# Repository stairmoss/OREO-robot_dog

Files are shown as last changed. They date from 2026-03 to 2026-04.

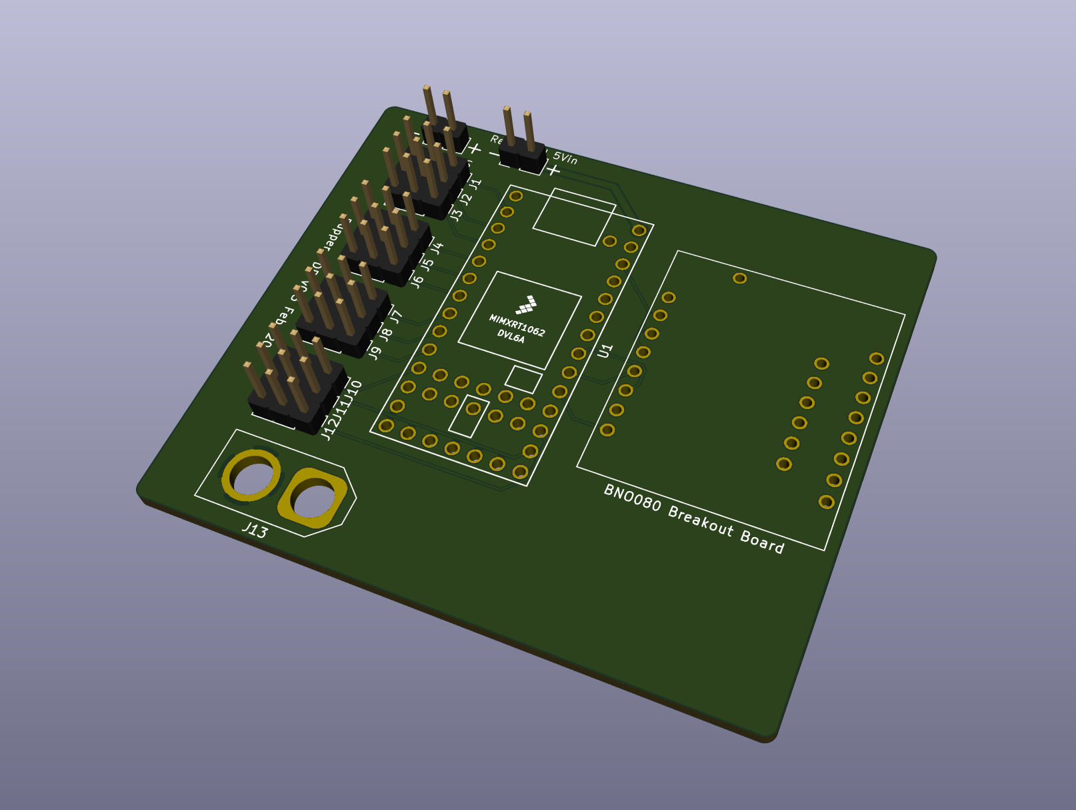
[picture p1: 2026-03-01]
3dpcbmodel.png

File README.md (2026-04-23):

# OREO – ROS Based Quadruped Robot Dog

# OREO V2 – ROS Powered Vision-Based Quadruped Robot  
### Hack Club Advanced Robotics Project

OREO V2 is a next-generation quadruped robot dog powered by a Raspberry Pi 4 and Teensy microcontroller, upgraded from the original ESP32 version into a full ROS-based intelligent robotic platform.

This version adds:

- 🧠 Computer Vision
- 🐾 12 High-Torque (20kg) Servos
- 🤖 ROS 2 Architecture
- 📡 Behavior-Based Control System
- ❤️ Touch Interaction
- 📷 Person Detection & Following

OREO V2 is no longer just a walking robot — it is an intelligent robotic companion platform built under a constrained $395 budget.

---

# 📌 Project Overview

| Item | Description |
|---|---|
| Robot Type | Quadruped (4-legged) |
| Architecture | ROS 2 Modular System |
| Main Computer | Raspberry Pi 4 Model B (4GB) |
| Motor Controller | Teensy Microcontroller |
| Servos per Leg | 3 (Hip, Upper, Knee) |
| Total Servos | 12 × 20kg High Torque |
| Sensors | IMU + Touch Sensor + Camera |
| Frame | 3D Printed Spot Micro Style |
| Power | 2S/3S Li-ion / LiPo Battery |
| Budget | ~$395 USD |
| Difficulty | Intermediate → Advanced |

---

# 🎯 Vision & Purpose

OREO V2 was built to:

- Transition from beginner robotics to ROS-based research structure
- Integrate computer vision into a quadruped platform
- Maintain affordability under strict budget constraints
- Build a modular robotic system expandable to SLAM and AI
- Learn real robotics engineering workflow

This robot is designed as a stepping stone toward advanced robotic systems.

---

# 🧠 System Architecture

OREO V2 uses a layered robotics architecture.

## 🔵 High-Level Control (Raspberry Pi 4)

Runs:

- Ubuntu 22.04 (64-bit)
- ROS 2 Humble
- OpenCV
- Behavior Node
- Gait Controller Node
- Vision Node

Responsibilities:

- Computer vision
- State machine decisions
- Gait generation
- Touch reaction logic
- Serial communication with Teensy

---

## 🟢 Low-Level Control (Teensy)

Responsibilities:

- Servo PWM generation via PCA9685
- Reading IMU data
- Executing joint commands
- Sending feedback (IMU + joint states)

Communication via USB Serial to Raspberry Pi.

---

# 🤖 ROS Node Structure

## 1️⃣ teensy_interface_node
- Converts ROS messages to serial packets
- Publishes:
  - `/joint_states`
  - `/imu`
- Subscribes:
  - `/joint_targets`

---

## 2️⃣ gait_controller_node
- Generates walking/trot gait
- Uses IMU feedback for balance correction
- Publishes `/joint_targets`

---

## 3️⃣ vision_node
- Captures camera feed
- Runs OpenCV person detection
- Publishes:
  - `/person_detected`
  - `/target_direction`

---

## 4️⃣ behavior_node (Robot Brain)

Handles states:

- IDLE
- SEARCH
- FOLLOW
- SIT
- HAPPY
- LOW_BATTERY

Input:
- Vision topic
- Touch topic
- Battery monitoring

Output:
- `/cmd_gait`
- Emotion state commands

---

## 5️⃣ touch_node
Reads capacitive or pressure sensor  
Publishes `/touch_event`  

When touched → Robot enters HAPPY state.

---

# ✨ Features

- 🐕 Full 12 DOF quadruped
- ⚙️ 20kg high torque servos
- 📷 Real-time person detection
- 🚶 Follow-human functionality
- ❤️ Touch-based interaction
- 📐 IMU-based balance correction
- 🔋 Dedicated high-current servo rail
- 🧩 Modular ROS architecture
- 🔌 Teensy real-time motor control
- 🧠 AI-expandable platform

---

# 🧩 Mechanical Design

Based on improved Spot Micro style frame.

## Body
- Central frame housing electronics
- Battery compartment protected
- Ventilation for Raspberry Pi
- Camera mount on head

## Legs
- 3 DOF per leg
- Parallel linkage for better weight distribution
- Reinforced servo mounts for 20kg servos
- Proper torque alignment to reduce mechanical stress

---

# 🔋 Power System

- 2S or 3S Li-ion pack
- High-current BEC or buck converter for servos (6V recommended)
- Separate regulated 5V rail for Raspberry Pi

⚠ Always:
- Measure voltage before connecting servos
- Test load voltage drop
- Never power servos directly from Raspberry Pi

---

# 🛠 Assembly Workflow

## Step 1 – 3D Print Parts
- Body frame
- Leg assemblies (×4)
- Head mount
- Internal mounting brackets

## Step 2 – Mount Servos
- Center all 12 servos before installation
- Attach horns at neutral 90°
- Secure using metal gears and lock screws

## Step 3 – Install Electronics
- Mount Raspberry Pi
- Mount Teensy
- Connect PCA9685
- Connect IMU
- Install touch sensor on head/body

## Step 4 – Wiring
- Servo power rail separated
- Signal wires routed cleanly
- Verify ground common between Teensy & Pi

## Step 5 – Software Setup
- Install Ubuntu on Pi
- Install ROS 2
- Clone project repository
- Build workspace using colcon
- Flash Teensy firmware
- Connect via USB

## Step 6 – Calibration
- Zero joint angles
- Adjust trim offsets
- Test single leg motion
- Test gait without load
- Then test full body

---

# 📦 Bill of Materials (Approx Budget)

| Component | Qty |
|---|-----|
| Raspberry Pi 4 (4GB) | 1 |
| Teensy Microcontroller | 1 |
| PCA9685 Servo Driver | 1 |
| 20kg Metal Gear Servos | 12 |
| IMU Sensor | 1 |
| Camera Module | 1 |
| Touch Sensor | 1 |
| Battery Pack | 1 |
| Buck Converter | 1 |
| 3D Printed Parts | 1 Set |
| Screws & Inserts | Set |

Total Estimated Cost: ~$390–395 USD

---

# 🚀 Software Capabilities

Current:

- Basic walk
- Trot gait
- Person detection
- Follow mode
- Touch reaction mode

Future Upgrades:

- SLAM
- Obstacle detection
- AI voice recognition
- Depth camera integration
- Web dashboard control

---

# 🏁 What Makes OREO V2 Special

- Built under strict budget
- Uses ROS (research-level framework)
- Integrates vision and behavior logic
- Maintains affordable hardware
- Fully modular and expandable
- Combines mechanical + electrical + software engineering

OREO V2 is not just a robot dog.

It is a robotics learning platform engineered for serious development while staying budget-conscious.

---

---

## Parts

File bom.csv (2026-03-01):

Component | Quantity | Unit Cost (USD) | Total Cost (USD)
Raspberry Pi 4 Model B (4GB) | 1 | 55 | 55
Teensy 4.0 | 1 | 25 | 25
PCA9685 16-Channel Servo Driver | 1 | 8 | 8
20kg Metal Gear Servo Motor | 12 | 9 | 108
MPU6050 IMU Sensor | 1 | 5 | 5
Raspberry Pi Camera Module | 1 | 15 | 15
Capacitive Touch Sensor | 1 | 3 | 3
2S/3S Li-ion Battery Pack | 1 | 30 | 30
High Current BEC / Buck Converter (6V 10A) | 1 | 18 | 18
5V Buck Converter for Raspberry Pi | 1 | 8 | 8
3D Printing Filament (PLA/PETG ~1kg) | 1 | 20 | 20
Servo Mounting Brackets / Hardware Kit | 1 | 15 | 15
M3 Screws/Nuts/Threaded Inserts Set | 1 | 12 | 12
18650 Cells (for custom pack) | 2 | 7 | 14
18650 Battery Holder | 1 | 6 | 6
Cooling Fan for Raspberry Pi | 1 | 5 | 5
USB Cable (Pi to Teensy) | 1 | 3 | 3
Wires/Connectors/Heat Shrink | 1 | 10 | 10
Miscellaneous Buffer Budget | 1 | 20 | 20
TOTAL |  |  | 370

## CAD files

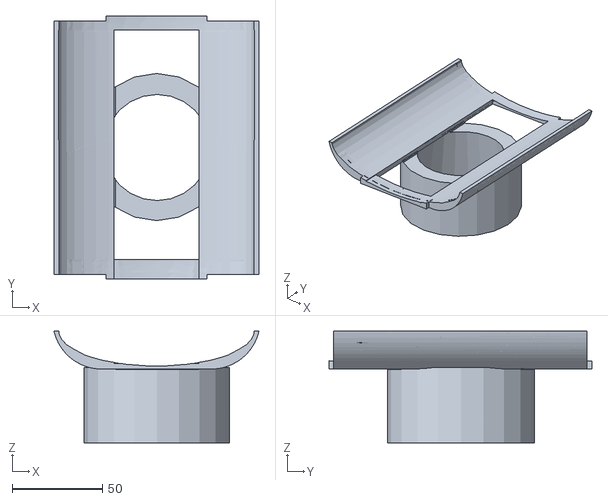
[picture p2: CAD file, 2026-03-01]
STL FILES/Stand_ConeCap.stl
113.3 x 145.4 x 61.6

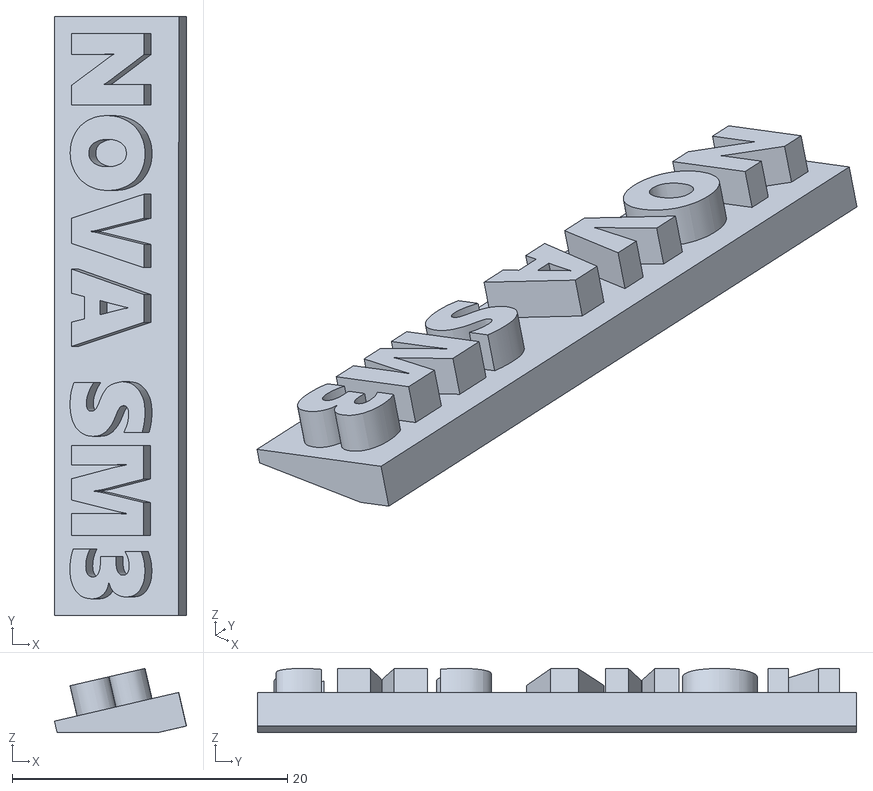
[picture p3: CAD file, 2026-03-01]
STL FILES/Cover_Emblem.stl
9.60 x 43.5 x 4.65

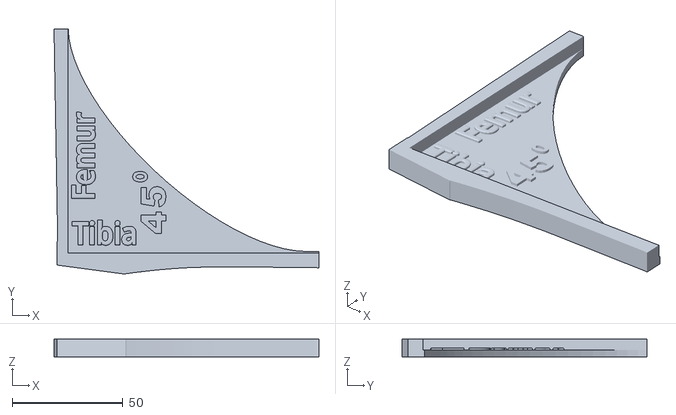
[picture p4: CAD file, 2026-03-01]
STL FILES/CalibrationTool.stl
119.4 x 110.6 x 8.00

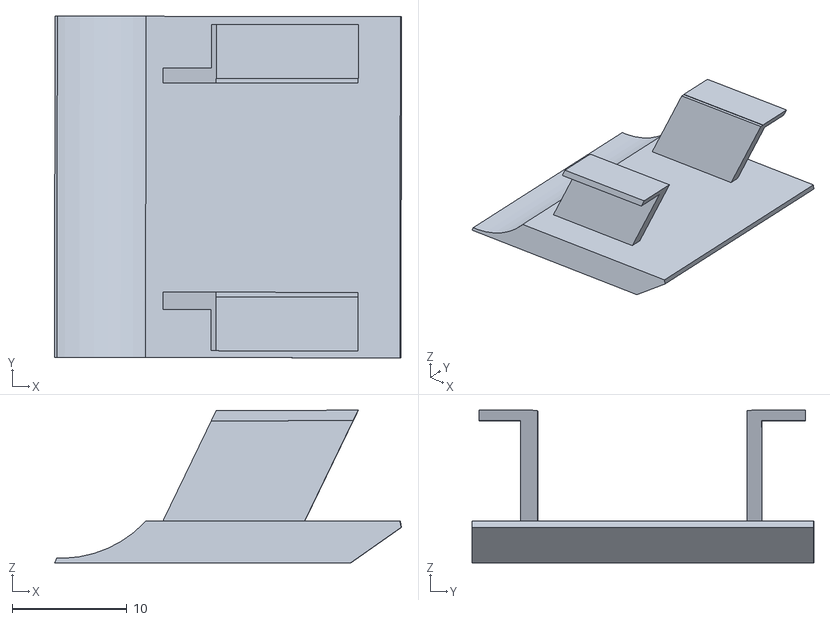
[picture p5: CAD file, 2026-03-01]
STL FILES/Cover_HeadPanelSlug.stl
30.2 x 29.7 x 13.3

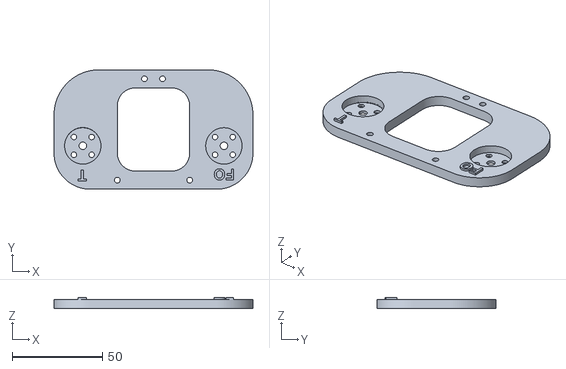
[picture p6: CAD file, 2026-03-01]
STL FILES/Frame_FrontShoulderOuter.stl
110.0 x 66.0 x 6.00

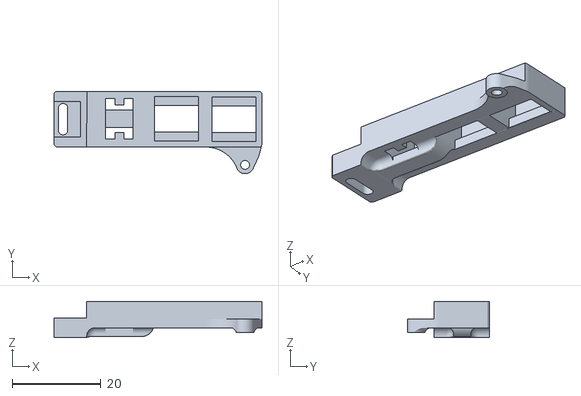
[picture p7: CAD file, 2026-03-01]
STL FILES/Cover_RearPanelBtnHolder_6x6LongBtn.stl
46.9 x 18.6 x 8.23

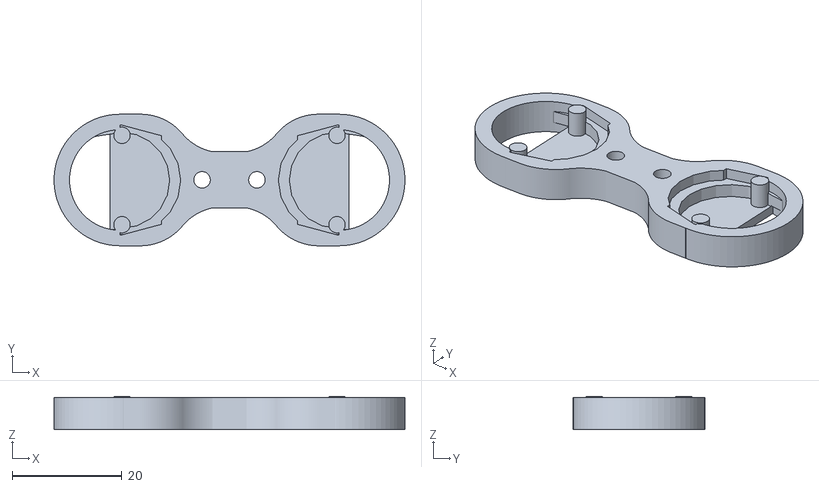
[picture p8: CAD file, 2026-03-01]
STL FILES/Sensor_RearPIRMount.stl
64.0 x 24.1 x 6.10

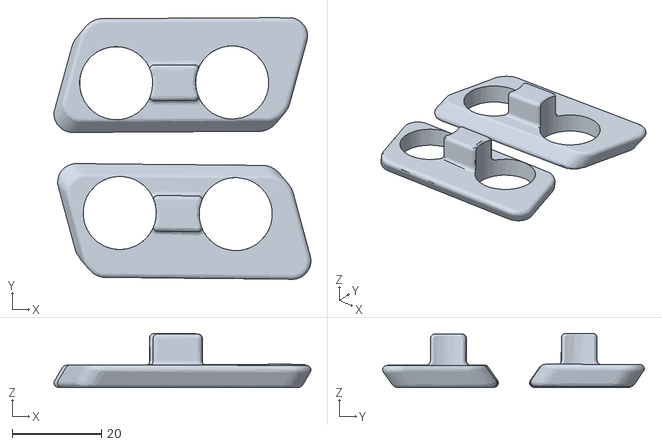
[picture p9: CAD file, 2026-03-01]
STL FILES/Sensor_UltraSonicPlate.stl
57.6 x 58.6 x 12.2

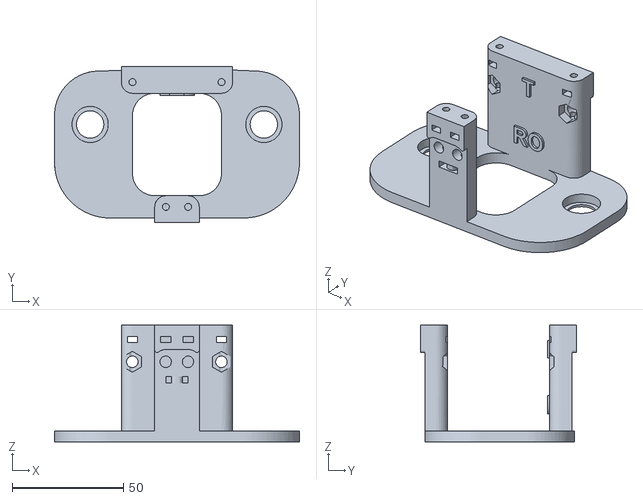
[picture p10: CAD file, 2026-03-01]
STL FILES/Frame_RearShoulderOuter.stl
110.0 x 70.0 x 52.5

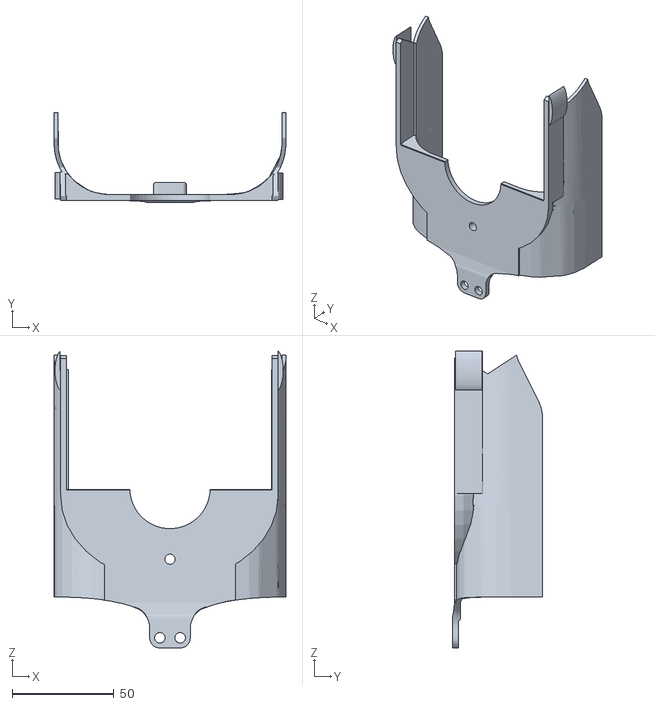
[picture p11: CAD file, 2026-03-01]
STL FILES/Cover_BottomRear.stl
114.0 x 44.4 x 146.1

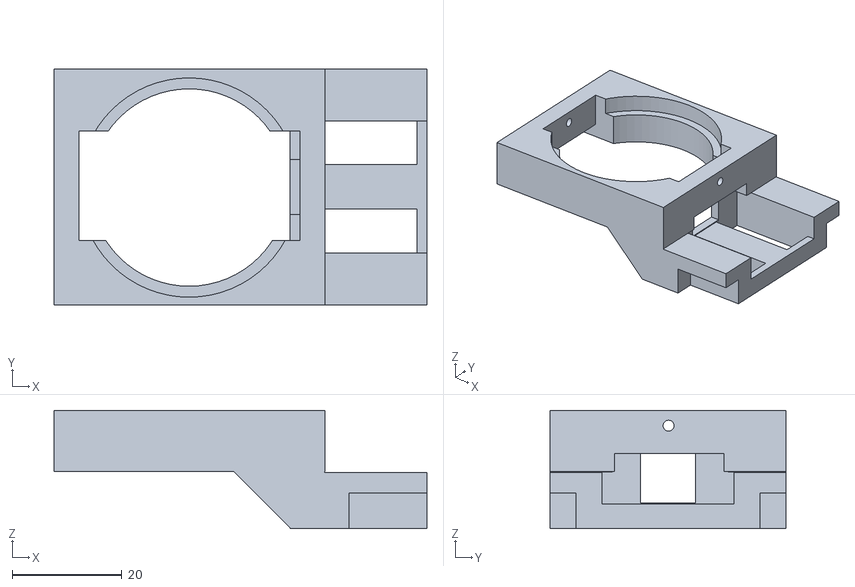
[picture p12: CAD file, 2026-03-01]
STL FILES/Mp3ProSpeakerMount.stl
68.0 x 43.0 x 21.6

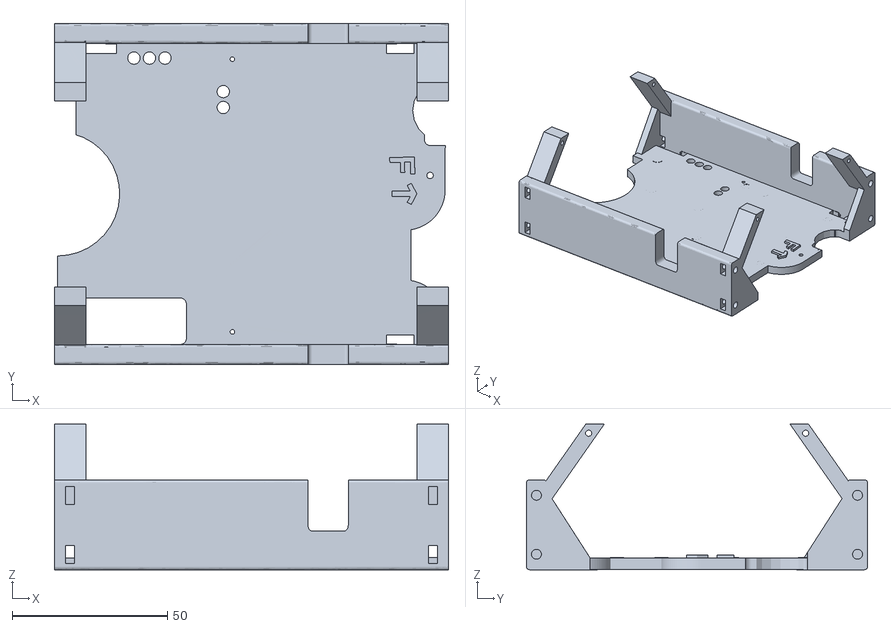
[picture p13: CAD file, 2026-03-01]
STL FILES/Frame_ChassisTrunk.stl
127.0 x 110.0 x 46.9

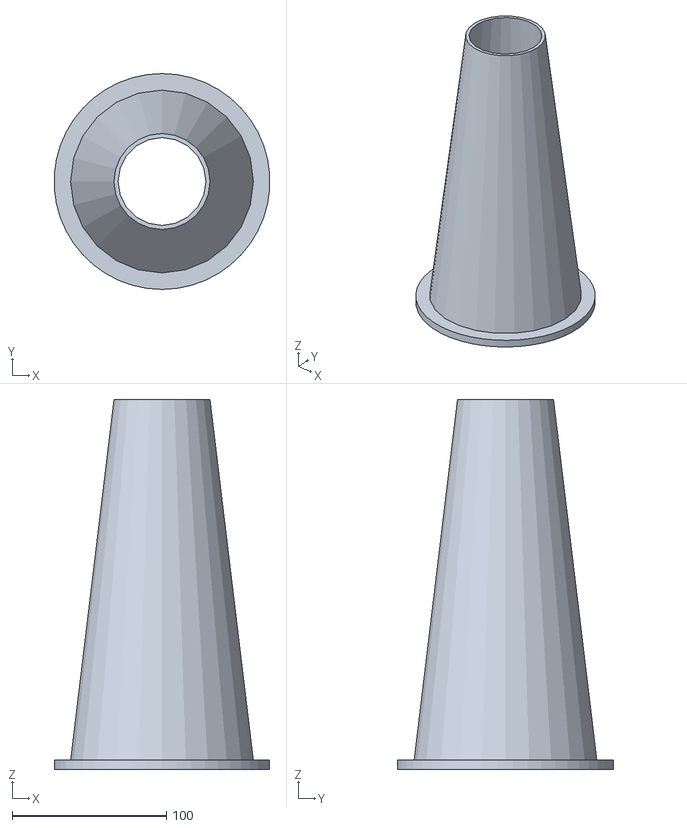
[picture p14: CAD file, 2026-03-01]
STL FILES/Stand_Cone.stl
139.7 x 140.0 x 240.0

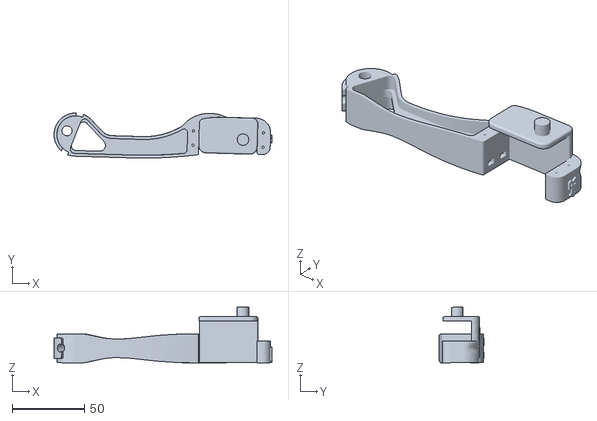
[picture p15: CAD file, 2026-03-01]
STL FILES/Frame_RightTibia.stl
151.0 x 31.3 x 38.5

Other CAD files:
STL FILES/Frame_FrontShoulderMiddle.stl
STL FILES/Frame_RightCoax.stl
STL FILES/Electronics_BuckConveterCase.stl
STL FILES/Stand_ConeBase.stl
STL FILES/Cover_BottomFront.stl
STL FILES/Cover_BottomHatch.stl
STL FILES/Cover_HeadPanel.stl
STL FILES/Cover_LeftFemur.stl
STL FILES/Cover_RearPanel_2Piece_Base.stl
STL FILES/Cover_RearPanel_2Piece_Shell.stl
STL FILES/Cover_RightFemur.stl
STL FILES/Cover_TopFront.stl
STL FILES/Cover_TopRear.stl
STL FILES/Foot.stl
STL FILES/Frame_FrontShoulderInner.stl
STL FILES/Frame_LeftCoax.stl
STL FILES/Frame_LeftFemur.stl
STL FILES/Frame_LeftTibia.stl
STL FILES/Frame_RearShoulderInner.stl
STL FILES/Frame_RearShoulderMiddle.stl
STL FILES/Frame_RightFemur.stl
STL FILES/Sensor_FrontPIRMount.stl
STL FILES/Sensor_MP3SpeakerMount.stl
STL FILES/Sensor_PIRCup.stl

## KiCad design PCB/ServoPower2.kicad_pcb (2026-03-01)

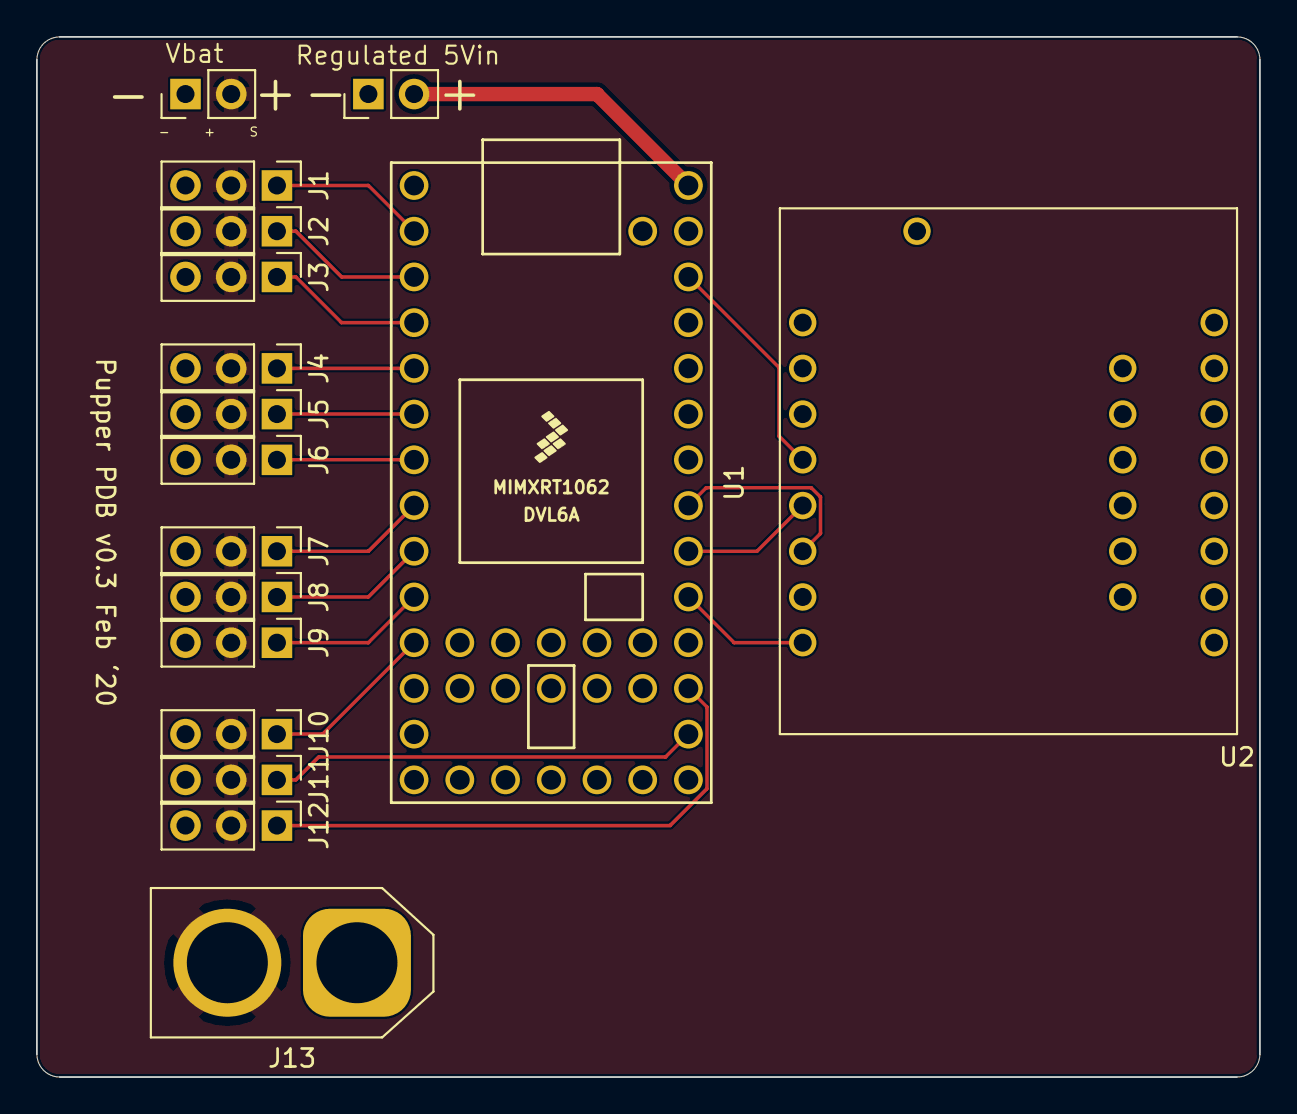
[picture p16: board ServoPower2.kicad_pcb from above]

Board: 2 copper layers, 67.9 x 57.8 mm, 17 parts (0 on the bottom side), 18 nets.

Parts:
J1, J2, J3, J4, J5, J6, J7, J8, J9, J10, J11, J12: Conn_01x03; PinHeader_1x03_P2.54mm_Vertical
J13: Conn_01x02; AMASS_XT60-M_1x02_P7.20mm_Vertical
J14, J15: Conn_01x02; PinHeader_1x02_P2.54mm_Vertical
U1: Teensy4.0; Teensy40
U2: IMUBN

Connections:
+5V: J15.2, U1.33
/INT: U1.24, U2.8
/S11: J1.1, U1.2
/S12: J2.1, U1.3
/S13: J3.1, U1.4
/S21: J4.1, U1.5
/S22: J5.1, U1.6
/S23: J6.1, U1.7
/S31: J7.1, U1.8
/S32: J8.1, U1.9
/S33: J9.1, U1.10
/S41: J10.1, U1.11
/S42: J11.1, U1.21
/S43: J12.1, U1.22
/SCL: U1.26, U2.6
/SDA: U1.25, U2.5
GND: J1.3, J2.3, J3.3, J4.3, J5.3, J6.3, J7.3, J8.3, J9.3, J10.3, J11.3, J12.3, J13.1, J14.1, J15.1, U1.1, U1.17, U1.32, U2.3
VDD: J1.2, J2.2, J3.2, J4.2, J5.2, J6.2, J7.2, J8.2, J9.2, J10.2, J11.2, J12.2, J13.2, J14.2

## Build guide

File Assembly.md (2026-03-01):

# 🦾 OREO V2 Assembly & Configuration Guide

This document provides the step-by-step instructions for the physical assembly and wiring of the OREO V2 Quadruped using the Raspberry Pi 4 and Teensy 4.0 breakout system.

---

## 🛠 1. Hardware Assembly

### **Phase A: Mechanical Build**
1. **Servo Centering:** Connect your **Teensy 4.0** to the **PCA9685**. Power the PCA9685 with your 6V buck converter. Run a "Center" script to move all 12 servos to exactly 90°.
2. **Leg Construction:** * Attach the **Tibia** (lower leg) to the **Femur** (upper leg).
   * Attach the Femur to the **Coxa** (hip/shoulder).
   * Ensure the leg is at a right angle (90°) when the servo is at its center position.
3. **Chassis:** Mount the **Raspberry Pi 4** and **Teensy 4.0** on the main body. Use standoffs to ensure the boards don't touch the plastic directly to allow for airflow.

---

## 🔌 2. Wiring Logic (The Breakout System)

Since we are using standard breakout boards, follow this wiring map exactly:

### **Power Distribution**
* **Battery (2S/3S Li-ion)** -> **XT60 Connector**.
* **XT60** -> Splits to **Two Buck Converters**:
    1. **Buck 1 (6V 10A):** Connects to the **Screw Terminals** on the PCA9685 (Powers the 12 Servos).
    2. **Buck 2 (5V 3A):** Connects to the **USB-C port** of the Raspberry Pi 4.
* **Teensy 4.0:** Powered via the **USB Cable** connected to the Raspberry Pi 4.

### **Data Connections**
| Component | Pin on Teensy 4.0 | Pin on Module |
| :--- | :--- | :--- |
| **PCA9685** | Pin 18 (SDA) | SDA |
| **PCA9685** | Pin 19 (SCL) | SCL |
| **MPU6050** | Pin 18 (SDA) | SDA |
| **MPU6050** | Pin 19 (SCL) | SCL |
| **MPU6050** | GND / 3.3V | GND / 3.3V |

---

## 📂 3. ROS 2 Humble Project Structure

On your Raspberry Pi 4 (Ubuntu 22.04), your workspace should be organized as follows:

```text
oreo_ws/
└── src/
    └── oreo_robot/
        ├── package.xml
        ├── setup.py
        ├── oreo_robot/
        │   ├── __init__.py
        │   ├── gait_controller.py   # Walking logic/IK
        │   ├── serial_bridge.py      # Communication with Teensy
        │   └── vision_node.py        # Pi Camera tracking
        └── launch/
            └── robot.launch.py       # Starts all nodes at once

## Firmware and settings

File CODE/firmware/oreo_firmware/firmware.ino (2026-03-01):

#include <Wire.h>
#include <Adafruit_PWMServoDriver.h>
#include <MPU6050_tockn.h>

// PCA9685 setup
Adafruit_PWMServoDriver pwm = Adafruit_PWMServoDriver();
#define SERVO_FREQ 50 // Analog servos run at ~50Hz

// IMU setup
MPU6050 mpu6050(Wire);

// Failsafe variables
unsigned long lastCommandTime = 0;
const unsigned long FAILSAFE_TIMEOUT = 2000; // 2 seconds
bool isFailsafe = false;

// Servo Pulse constants (Adjust based on your 20kg servos)
#define SERVOMIN  150 // Minimum pulse length count (out of 4096)
#define SERVOMAX  500 // Maximum pulse length count (out of 4096)

void setup() {
  Serial.begin(115200);
  Wire.begin();
  
  // Initialize PCA9685
  pwm.begin();
  pwm.setOscillatorFrequency(27000000);
  pwm.setPWMFreq(SERVO_FREQ);

  // Initialize IMU
  mpu6050.begin();
  mpu6050.calcGyroOffsets(true);

  delay(10);
  lastCommandTime = millis();
}

// Convert degrees (0-180) to PCA9685 pulse
int degToPulse(int deg) {
  return map(deg, 0, 180, SERVOMIN, SERVOMAX);
}

void enterFailsafe() {
  if (!isFailsafe) {
    // Move to "Sit" position (Example: all legs 90 or specific angles)
    for (int i = 0; i < 16; i++) {
      pwm.setPWM(i, 0, 4096); // This turns off the pulse to "detach"
    }
    isFailsafe = true;
  }
}

void loop() {
  // 1. Handle Serial Input from Raspberry Pi
  if (Serial.available() > 0) {
    String data = Serial.readStringUntil('\n');
    if (data.startsWith("S,")) {
      isFailsafe = false;
      lastCommandTime = millis();
      
      // Parse CSV: S,a1,a2,a3...a12
      int angles[12];
      int currentIndex = 0;
      int startPos = 2; // Skip "S,"
      
      for (int i = 0; i < 12; i++) {
        int commaPos = data.indexOf(',', startPos);
        if (commaPos != -1) {
          angles[i] = data.substring(startPos, commaPos).toInt();
          startPos = commaPos + 1;
        } else {
          angles[i] = data.substring(startPos).toInt();
        }
        
        // Write to PCA9685 (Channels 0-11)
        pwm.setPWM(i, 0, degToPulse(angles[i]));
      }
    }
  }

  // 2. Failsafe Logic
  if (millis() - lastCommandTime > FAILSAFE_TIMEOUT) {
    enterFailsafe();
  }

  // 3. Stream IMU Data to Pi (50Hz)
  static unsigned long lastIMUTime = 0;
  if (millis() - lastIMUTime > 20) {
    mpu6050.update();
    Serial.print("IMU,");
    Serial.print(mpu6050.getAngleX()); // Pitch
    Serial.print(",");
    Serial.println(mpu6050.getAngleY()); // Roll
    lastIMUTime = millis();
  }
}

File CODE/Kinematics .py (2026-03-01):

import rclpy
from rclpy.node import Node
from geometry_msgs.msg import Twist
from std_msgs.msg import Int32MultiArray
import math
import numpy as np

class OreoKinematics:
    """3-DOF Inverse Kinematics for OREO Leg"""
    def __init__(self, L_coxa=40, L_femur=100, L_tibia=100):
        self.L1 = L_coxa
        self.L2 = L_femur
        self.L3 = L_tibia

    def solve_ik(self, x, y, z):
        # Angle 1: Coxa (Hip Yaw)
        theta1 = math.atan2(y, x)
        
        # Distance in XY plane from coxa joint to foot
        r = math.sqrt(x**2 + y**2) - self.L1
        
        # Distance from shoulder (femur joint) to foot in the R-Z plane
        s = math.sqrt(r**2 + z**2)
        
        # Cosine rule for Theta3 (Tibia)
        cos_theta3 = (self.L2**2 + self.L3**2 - s**2) / (2 * self.L2 * self.L3)
        cos_theta3 = max(-1, min(1, cos_theta3)) # Clamp
        theta3 = math.acos(cos_theta3)
        
        # Theta2 (Femur)
        phi1 = math.atan2(z, r)
        phi2 = math.acos((self.L2**2 + s**2 - self.L3**2) / (2 * self.L2 * s))
        theta2 = phi1 + phi2

        # Convert to degrees and shift to 0-180 range (approx)
        return [
            math.degrees(theta1) + 90,
            math.degrees(theta2) + 90,
            math.degrees(theta3)
        ]

class GaitManagerNode(Node):
    def __init__(self):
        super().__init__('gait_manager_node')
        self.publisher_ = self.create_publisher(Int32MultiArray, '/joint_angles', 10)
        self.subscription = self.create_subscription(Twist, '/cmd_vel', self.cmd_vel_callback, 10)
        
        self.ik = OreoKinematics()
        self.timer = self.create_timer(0.02, self.update_gait) # 50Hz
        
        self.velocity = 0.0
        self.step_height = 30.0
        self.t = 0.0 # Time phase

    def cmd_vel_callback(self, msg):
        self.velocity = msg.linear.x

    def update_gait(self):
        # Very simplified Trot Gait Logic
        # Each leg moves in a sine wave trajectory
        # Leg 0 & 3 (Group A), Leg 1 & 2 (Group B)
        
        angles = []
        # Normal standing height Z = -120
        base_z = -120 
        
        # Calculate X/Z offsets based on time t and velocity
        phase_a = math.sin(self.t)
        phase_b = math.sin(self.t + math.pi)
        
        for i in range(4):
            # Alternate legs
            p = phase_a if i in [0, 3] else phase_b
            
            x = self.velocity * p * 50  # Stride length
            z = base_z + (abs(p) * self.step_height if p > 0 else 0)
            y = 0 # Assume straight line
            
            angles.extend(self.ik.solve_ik(x + 50, y, z)) # Offset x by 50 for neutral pos

        msg = Int32MultiArray()
        msg.data = [int(a) for a in angles]
        self.publisher_.publish(msg)
        self.t += 0.2 # Speed of gait cycle

def main(args=None):
    rclpy.init(args=args)
    node = GaitManagerNode()
    rclpy.spin(node)
    node.destroy_node()
    rclpy.shutdown()

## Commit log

2025-12-25 Oreo robot dog project
    about the Oreo robot dog project, including design, assembly instructions, and components.
2025-12-25 Add assembly guide for OREO robot dog
    This document provides a comprehensive guide on assembling the OREO robot dog, detailing the tools, parts checklist, and step-by-step instructions for assembly, wiring, and testing.
2026-01-19 Rename i2cscan.ino to code /i2cscan.ino
2026-01-19 Rename imu.ino to code /imu.ino
2026-01-19 Rename powerSensor.ino to code /powerSensor.ino
2026-01-19 Rename Robot Dog Boston V1.brd to PCB/Robot Dog Boston V1.brd
    [Robot Dog Boston V1.brd]
2026-01-19 Update and rename Robot Dog Boston V1.kicad_pcb to PCB /Robot Dog Boston V1.kicad_pcb
    [Robot Dog Boston V1.kicad_pcb]
2026-01-19 Rename Robot Dog Boston V1.kicad_prl to PCB /Robot Dog Boston V1.kicad_prl
2026-01-19 Rename Robot Dog Boston V1.kicad_pro to PCB /Robot Dog Boston V1.kicad_pro
2026-01-19 Rename Robot Dog Boston V1.sch to PCB /Robot Dog Boston V1.sch
    [Robot Dog Boston V1.sch]
2026-01-19 Revise README for OREO robot dog project
    Updated README to provide detailed project overview, features, assembly instructions, and BOM for the OREO quadruped robot dog.
2026-03-01 Revise README for OREO V2 ROS Quadruped Robot
    Updated project description and specifications for OREO V2, transitioning from ESP32 to ROS-based architecture with enhanced features.
2026-03-01 Update and rename PCB /Robot Dog Boston V1.kicad_pcb to v1/PCB Robot pcb/Dog Boston V1.kicad_pcb
    [Dog Boston V1.kicad_pcb]
2026-03-01 Rename index.html to stl file /index.html
2026-03-01 Convert BOM to CSV format
    Updated BOM format to use CSV standard with commas.
    [bom.csv]
2026-03-01 Revise OREO V2 Assembly & Configuration Guide
    Updated assembly guide to focus on hardware assembly and wiring instructions for OREO V2. Revised sections for clarity and added detailed steps for mechanical build and wiring logic.
